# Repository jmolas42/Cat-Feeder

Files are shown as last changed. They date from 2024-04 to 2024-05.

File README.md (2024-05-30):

# Cat-Feeder

## Distributeur automatique de nourriture pour chat

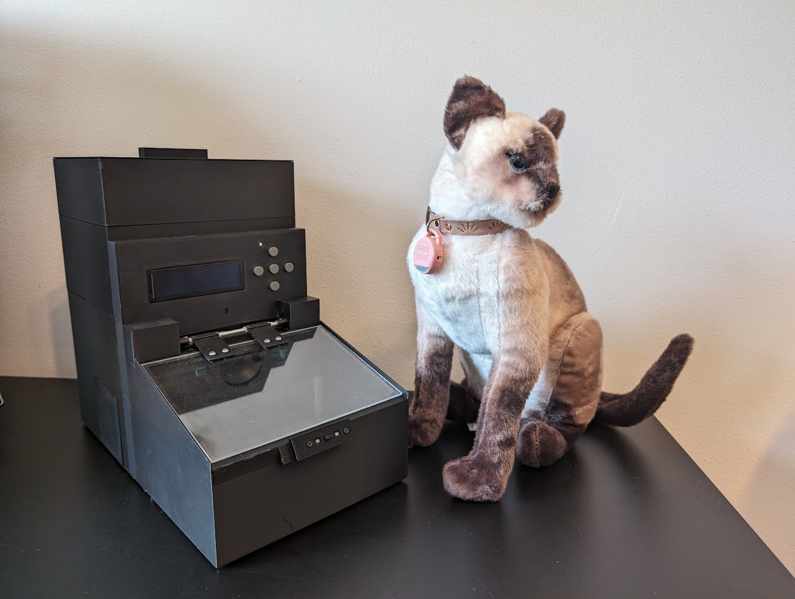
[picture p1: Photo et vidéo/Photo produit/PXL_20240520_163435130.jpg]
Cat Feeder


Préparez-vous à une innovation majeure dans la gestion alimentaire de vos compagnons félins ! Le distributeur automatique pour chats est une solution ingénieuse qui prend en charge la nourriture de votre animal de compagnie de manière autonome et efficace. Plus besoin de vous soucier des repas de votre chat, laissez cet appareil révolutionnaire s'occuper de tout, vous offrant ainsi une tranquillité d'esprit totale. Avec cette technologie de pointe, simplifiez votre quotidien et offrez à votre félin une expérience alimentaire optimale, tout en vous concentrant sur les moments importants de la vie.

## Gestion automatique et sécurisée pour les repas de votre chat

### Fonctionnalités :
- **Entièrement configurable** : Ajustez les paramètres selon les besoins spécifiques de votre chat.
- **Distribution automatique des croquettes à certaines heures** : Assure une alimentation régulière et équilibrée.
- **Porte qui s’ouvre seulement pour le chat autorisé** : Grâce à une balise dans le cou du chat, garantissant un accès sécurisé à la nourriture.
- **Connecté au WiFi** : Permet une gestion à distance et synchronisation des horaires.
- **Balance intégrée** : Surveille le poids du bol et enregistre l’appétit du chat via un site web dédié.
- **Système de secours pour l’alimentation** : Fonctionne avec des piles en cas de coupure de courant, assurant une continuité de service.

## Installation et Configuration :
1. **Insérez les piles** dans le distributeur et la balise pour assurer leur bon fonctionnement.
2. **Configurez l'appareil** une fois pour définir les heures de distribution des repas et les paramètres personnalisés.
3. **Profitez** de la gestion automatisée des repas de votre chat, offrant une alimentation régulière et surveillée.

Avec le Cat-Feeder, offrez à votre félin une alimentation optimisée et simplifiez-vous la vie !

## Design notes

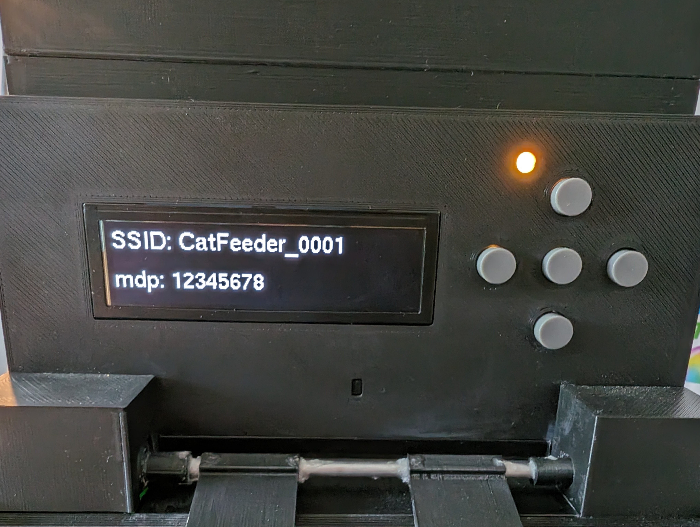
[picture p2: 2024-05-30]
Photo et vidéo/Photo produit/PXL_20240529_175449624.MP.jpg

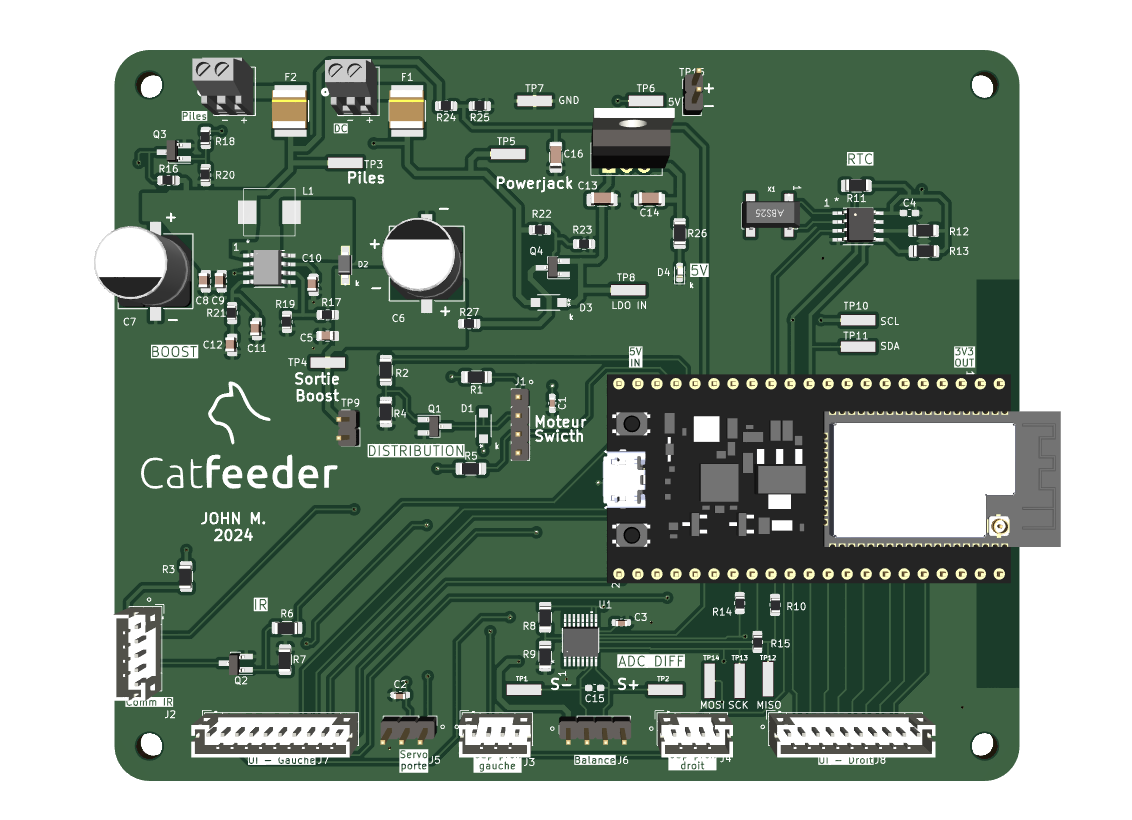
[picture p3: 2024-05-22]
Photo et vidéo/Photo PCB/PCB distributeur.png

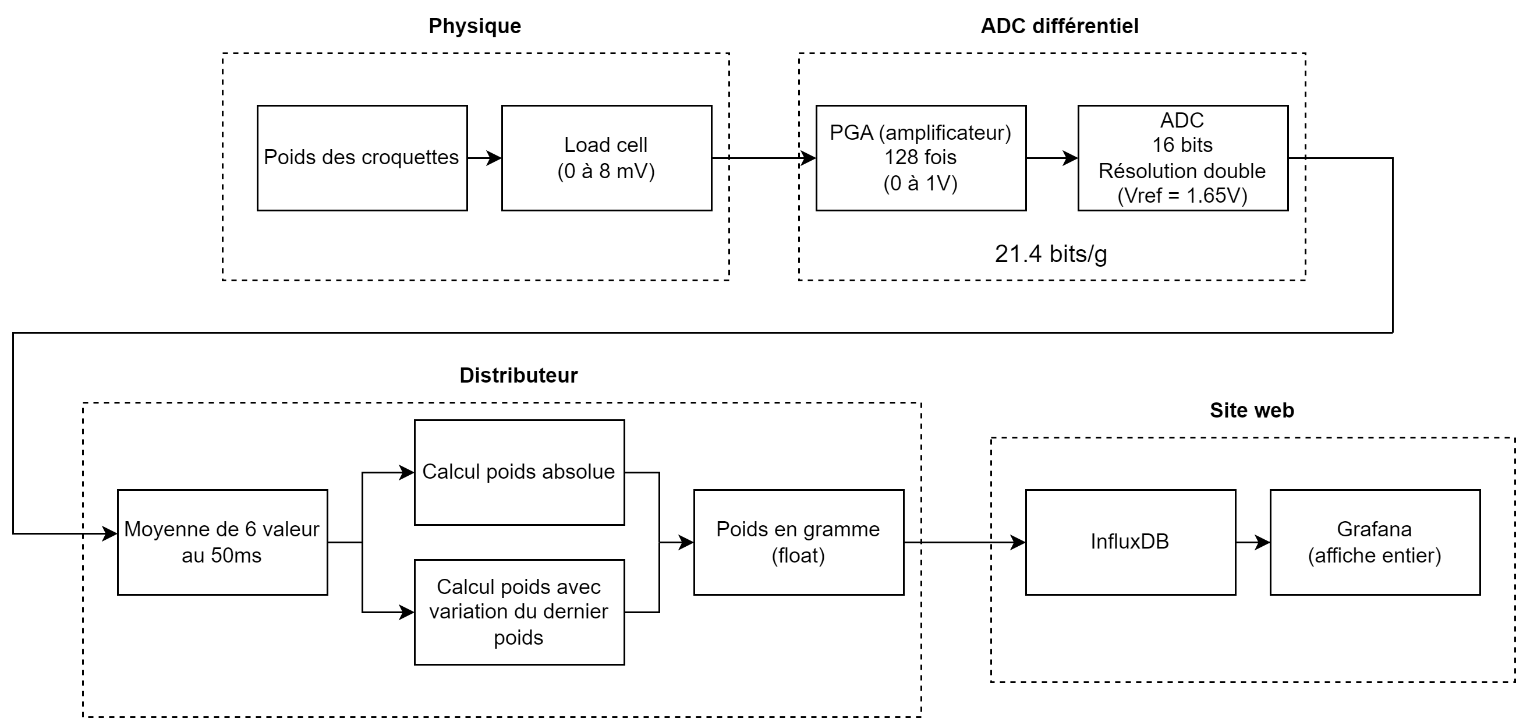
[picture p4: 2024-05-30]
Schémas/Schéma de principes/schema_balance.png

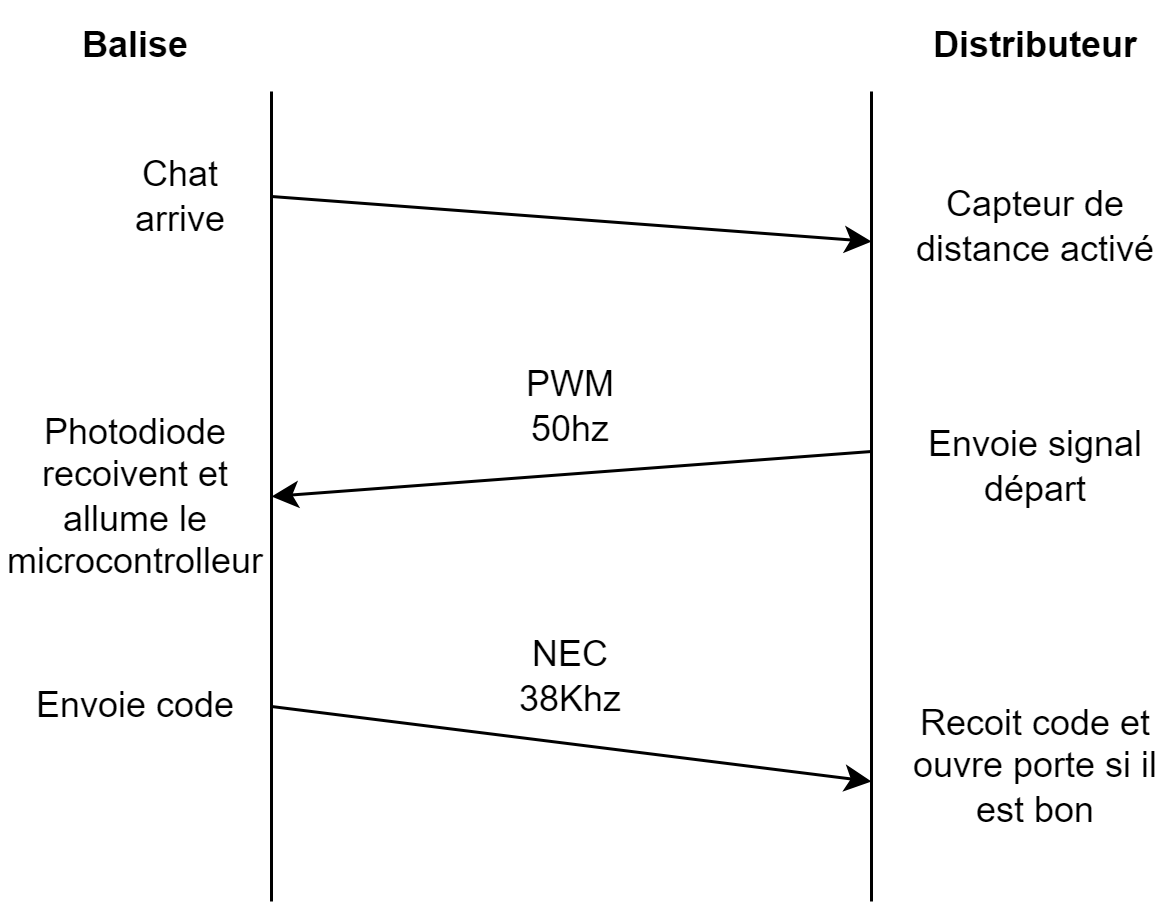
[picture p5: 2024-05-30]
Schémas/Schéma de principes/comm IR.drawio.png

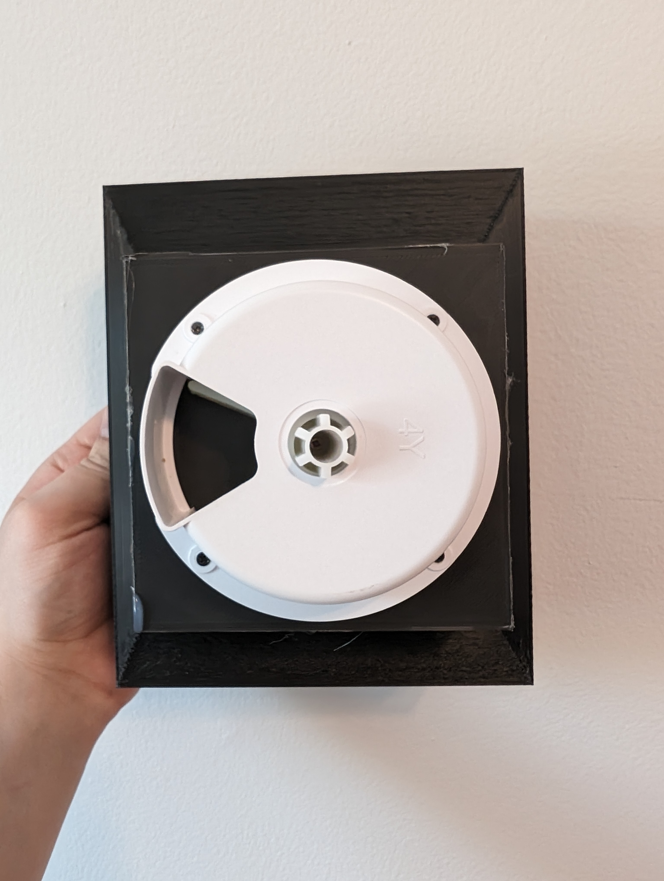
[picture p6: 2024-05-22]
Photo et vidéo/Photo produit/PXL_20240522_155029285.NIGHT.jpg

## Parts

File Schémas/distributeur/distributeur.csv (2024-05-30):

# | Reference | Qty | Value | Footprint | DNP
1 | C1, C2, C3, C4, C15 | 5 | ~ | Capacitor_SMD:C_0603_1608Metric_Pad1.08x0.95mm_HandSolder
2 | C5, C8 | 2 | 10u | Capacitor_SMD:C_0805_2012Metric_Pad1.18x1.45mm_HandSolder
3 | C6, C7 | 2 | 470u | cap_dig:CAP_EEE_G_PAN-M
4 | C9 | 1 | 1u | Capacitor_SMD:C_0805_2012Metric_Pad1.18x1.45mm_HandSolder
5 | C10 | 1 | 10n | Capacitor_SMD:C_0805_2012Metric_Pad1.18x1.45mm_HandSolder
6 | C11 | 1 | 47p | Capacitor_SMD:C_0805_2012Metric_Pad1.18x1.45mm_HandSolder
7 | C12 | 1 | 2.2n | Capacitor_SMD:C_0805_2012Metric_Pad1.18x1.45mm_HandSolder
8 | C13 | 1 | 1u | Capacitor_SMD:C_1206_3216Metric_Pad1.33x1.80mm_HandSolder
9 | C14 | 1 | 10u | Capacitor_SMD:C_1206_3216Metric_Pad1.33x1.80mm_HandSolder
10 | D1, D3 | 2 | 1N4007FL | 1n4007:CR_SOD-123FL_SME-M
11 | D2 | 1 | SS34LW | SS34LWH:SODFL3718X102N
12 | D4 | 1 | LED | LED_SMD:LED_0603_1608Metric_Pad1.05x0.95mm_HandSolder
13 | F1, F2 | 2 | Fuse | MF_SMDF050_2:FUSE_SMDF050-2
14 | J1 | 1 | Distribution | Connector_PinHeader_2.54mm:PinHeader_1x04_P2.54mm_Vertical
15 | J2 | 1 | ~ | Connector_JST:JST_PH_B5B-PH-K_1x05_P2.00mm_Vertical
16 | J3, J4 | 2 | ~ | Connector_JST:JST_PH_B4B-PH-K_1x04_P2.00mm_Vertical
17 | J5 | 1 | Servomoteur porte | Connector_PinHeader_2.54mm:PinHeader_1x03_P2.54mm_Vertical
18 | J6 | 1 | Cellule de charge | Connector_PinHeader_2.54mm:PinHeader_1x04_P2.54mm_Vertical
19 | J7, J8 | 2 | Conn_01x10 | Connector_JST:JST_PH_B10B-PH-K_1x10_P2.00mm_Vertical
20 | J9 | 1 | Powerjack | OST:CONN_OSTVN02A150_OST
21 | J10 | 1 | Piles | OST:CONN_OSTVN02A150_OST
22 | L1 | 1 | 6.8u | Library:TMPA 0603S
23 | Q1, Q2, Q3 | 3 | PJA3432-AU_R1 | Package_TO_SOT_SMD:SOT-23_Handsoldering
24 | Q4 | 1 | DMP3068L | Package_TO_SOT_SMD:SOT-23_Handsoldering
25 | R1 | 1 | 0R | Resistor_SMD:R_1206_3216Metric_Pad1.30x1.75mm_HandSolder
26 | R2, R6 | 2 | 100 | Resistor_SMD:R_1206_3216Metric_Pad1.30x1.75mm_HandSolder
27 | R3 | 1 | 51 | Resistor_SMD:R_1206_3216Metric_Pad1.30x1.75mm_HandSolder
28 | R4, R5, R7, R11, R12, R13 | 6 | 10k | Resistor_SMD:R_1206_3216Metric_Pad1.30x1.75mm_HandSolder
29 | R8 | 1 | 330k | Resistor_SMD:R_1206_3216Metric_Pad1.30x1.75mm_HandSolder
30 | R9 | 1 | 510k | Resistor_SMD:R_1206_3216Metric_Pad1.30x1.75mm_HandSolder
31 | R10, R14, R15, R27 | 4 | 0R | Resistor_SMD:R_0805_2012Metric_Pad1.20x1.40mm_HandSolder
32 | R16, R19, R23 | 3 | 10k | Resistor_SMD:R_0805_2012Metric_Pad1.20x1.40mm_HandSolder
33 | R17 | 1 | 34.9k | Resistor_SMD:R_0805_2012Metric_Pad1.20x1.40mm_HandSolder
34 | R18, R22 | 2 | 100 | Resistor_SMD:R_0805_2012Metric_Pad1.20x1.40mm_HandSolder
35 | R20 | 1 | 1k | Resistor_SMD:R_0805_2012Metric_Pad1.20x1.40mm_HandSolder
36 | R21 | 1 | 51k | Resistor_SMD:R_0805_2012Metric_Pad1.20x1.40mm_HandSolder
37 | R24 | 1 | 230k | Resistor_SMD:R_0805_2012Metric_Pad1.20x1.40mm_HandSolder
38 | R25 | 1 | 510k | Resistor_SMD:R_0805_2012Metric_Pad1.20x1.40mm_HandSolder
39 | R26 | 1 | 1.5k | Resistor_SMD:R_1206_3216Metric_Pad1.30x1.75mm_HandSolder
40 | TP1, TP2, TP3, TP4, TP5, TP6, TP7, TP8, TP10, TP11, TP12, TP13, TP14 | 13 | ~ | RCWCTE:TP420X150
41 | TP15 | 1 | 5V | Connector_PinHeader_2.54mm:PinHeader_1x02_P2.54mm_Vertical
42 | U1 | 1 | MAX11213EEE+ | MAX11213:21-0055H_16_MXM-M
43 | U2 | 1 | DS1337S+T&R | DS1337:21-0041B_8_MXM-M
44 | U3 | 1 | ESP32-S2-Saola-1 | PCM_Espressif:ESP32-S2-Saola-1
45 | U4 | 1 | PAM2423AECADJR | pam_dig:SOP-8_PAM2423AECADJR_DIO-M
46 | U5 | 1 | MIC2940A 5V | Package_TO_SOT_THT:TO-220-3_Vertical
47 | X1 | 1 | 32.768KHz | ABS25_32_768KHZ_6_1_T:XTAL_ABS25-32.768KHZ-6-1-T

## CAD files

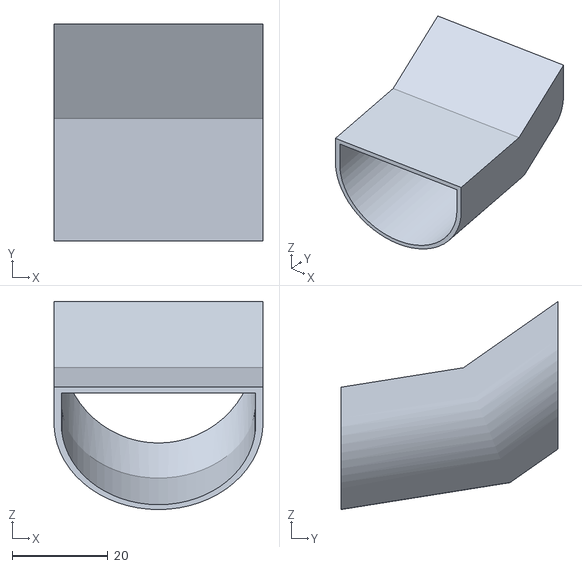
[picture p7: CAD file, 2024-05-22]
3D/chute croquette.stl
43.7 x 45.5 x 43.6

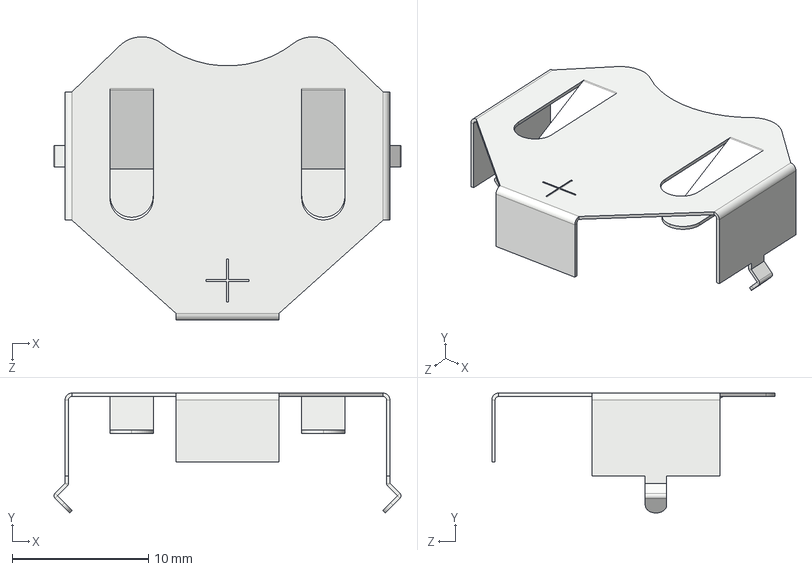
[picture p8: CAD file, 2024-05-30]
Schémas/Balise/3D/3011.step
25.5 x 8.80 x 20.8 mm

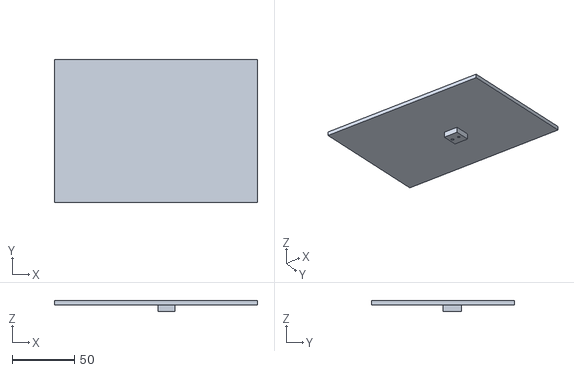
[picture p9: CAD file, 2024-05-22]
3D/support load cell - dessus.stl
163.7 x 115.7 x 8.50

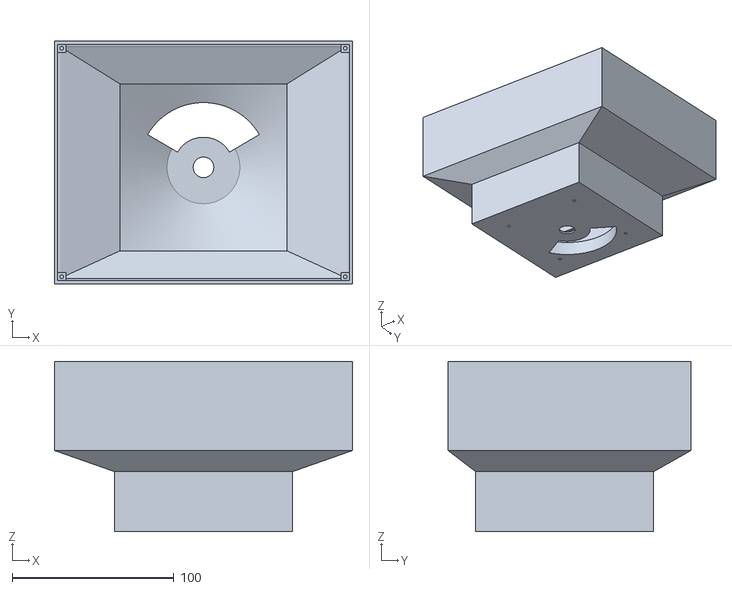
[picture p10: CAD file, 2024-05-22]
3D/réserve croquette.stl
184.0 x 150.0 x 105.0

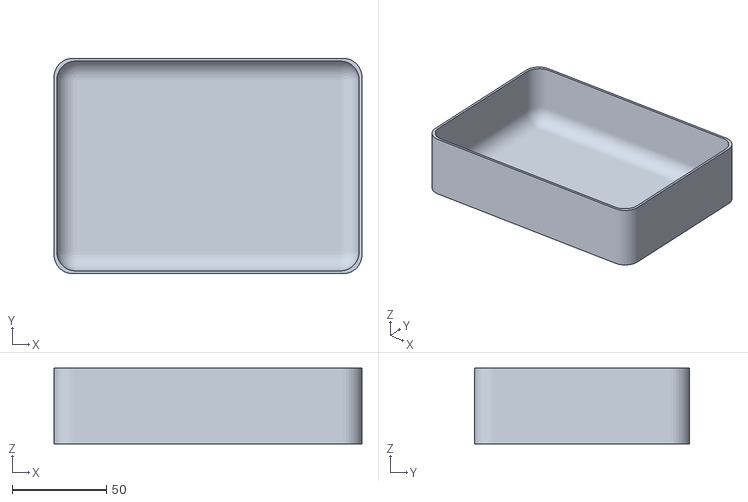
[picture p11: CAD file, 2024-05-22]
3D/bol.stl
163.0 x 114.0 x 40.0

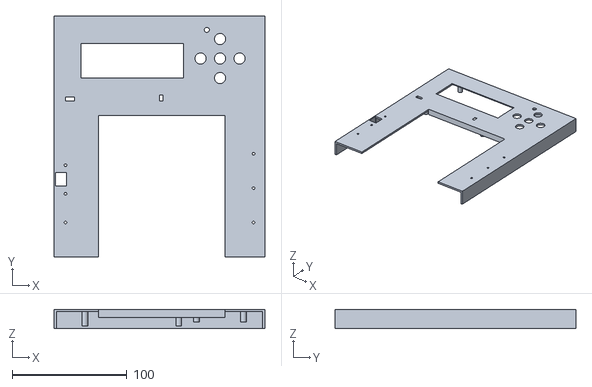
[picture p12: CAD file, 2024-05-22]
3D/face avant.stl
184.0 x 210.0 x 17.0

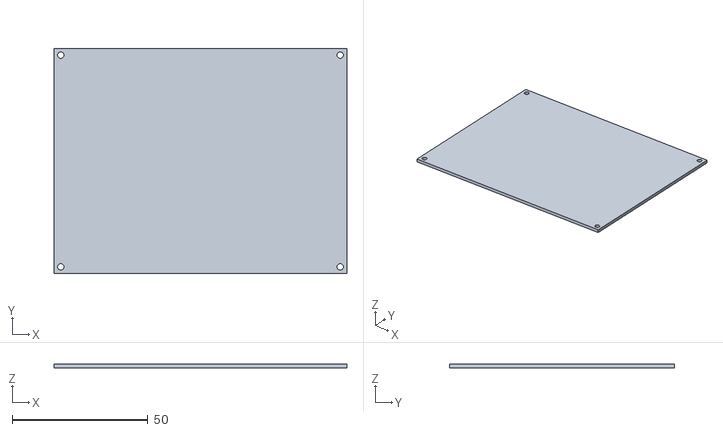
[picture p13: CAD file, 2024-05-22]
3D/porte holder batterie.stl
108.0 x 83.0 x 1.50

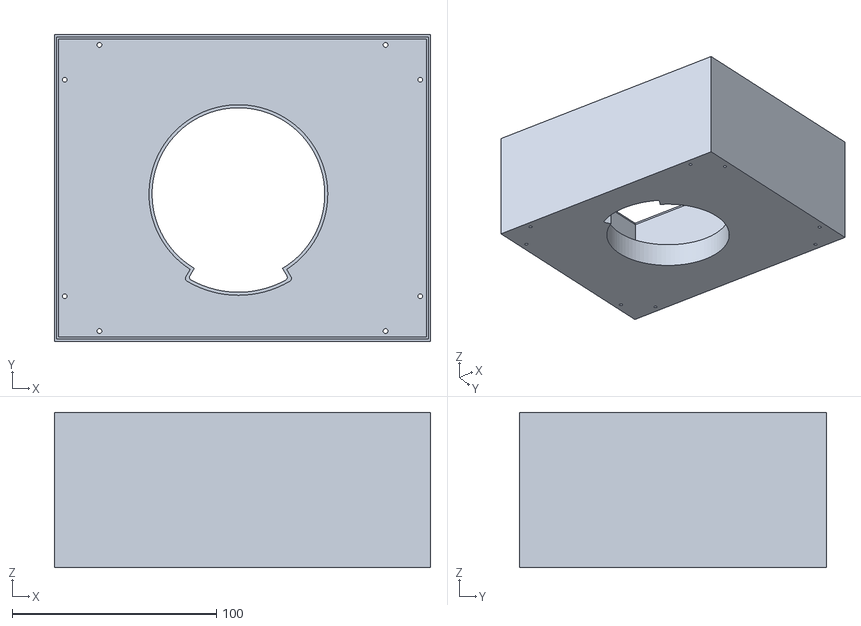
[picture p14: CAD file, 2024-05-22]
3D/base réserve bouffe.stl
184.0 x 150.0 x 75.9

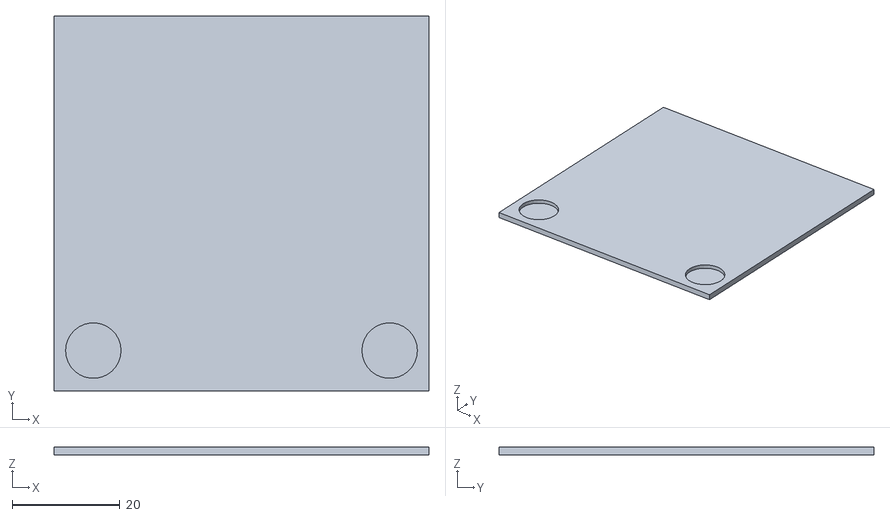
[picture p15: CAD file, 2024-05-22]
3D/porte distributrice arriere gauche avec aimant.stl
69.6 x 69.6 x 1.50

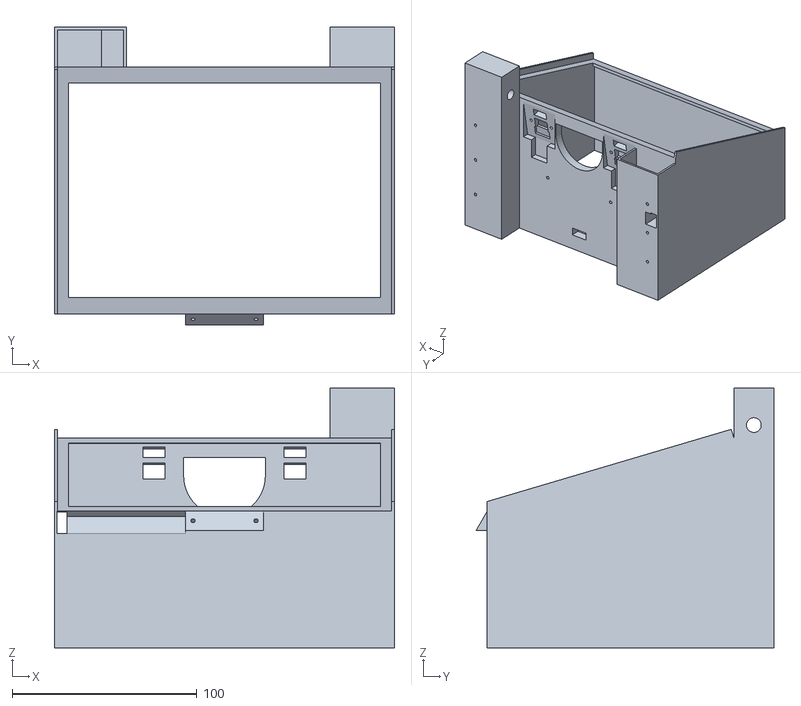
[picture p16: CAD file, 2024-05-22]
3D/devant distributrice.stl
184.0 x 161.1 x 140.6

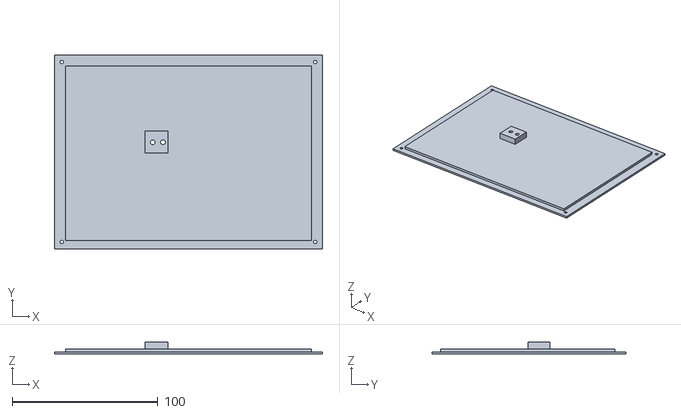
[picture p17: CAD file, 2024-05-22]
3D/support load cell - dessous.stl
184.0 x 133.5 x 8.50

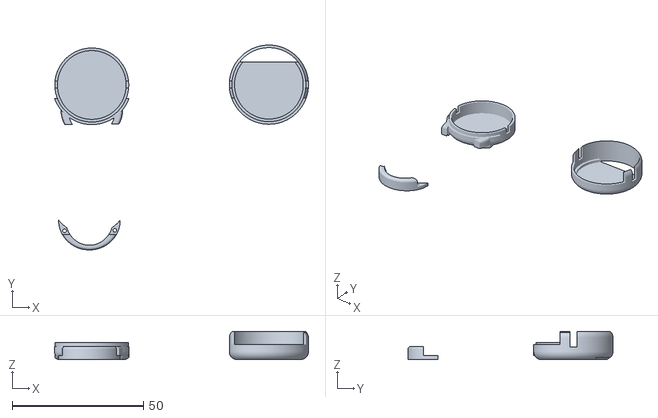
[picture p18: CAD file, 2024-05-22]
3D/boitier balise.stl
96.8 x 78.1 x 10.7

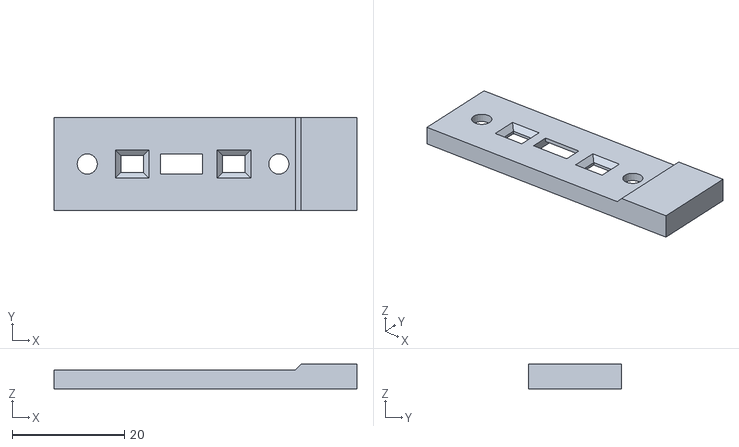
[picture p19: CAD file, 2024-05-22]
3D/cache PCB IR.stl
54.0 x 16.5 x 4.40

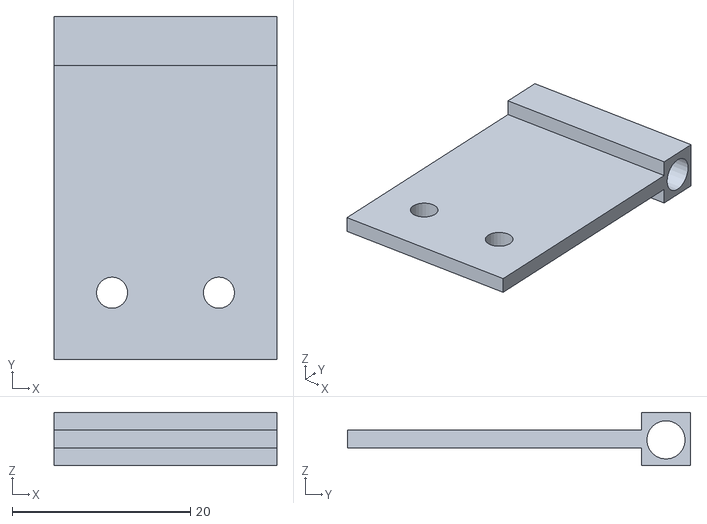
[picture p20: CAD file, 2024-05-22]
3D/serre porte.stl
25.0 x 38.5 x 6.00

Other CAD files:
3D/derriere distributrice.stl
3D/adapteur gougeon.stl
3D/cache servo.stl
3D/support additionnel vertical.stl
3D/adapteur servo.stl
3D/cache fils IR.stl
3D/couvercle réserve bouffe.stl
3D/plateau distribution.stl
3D/support additionnel horizontal.stl

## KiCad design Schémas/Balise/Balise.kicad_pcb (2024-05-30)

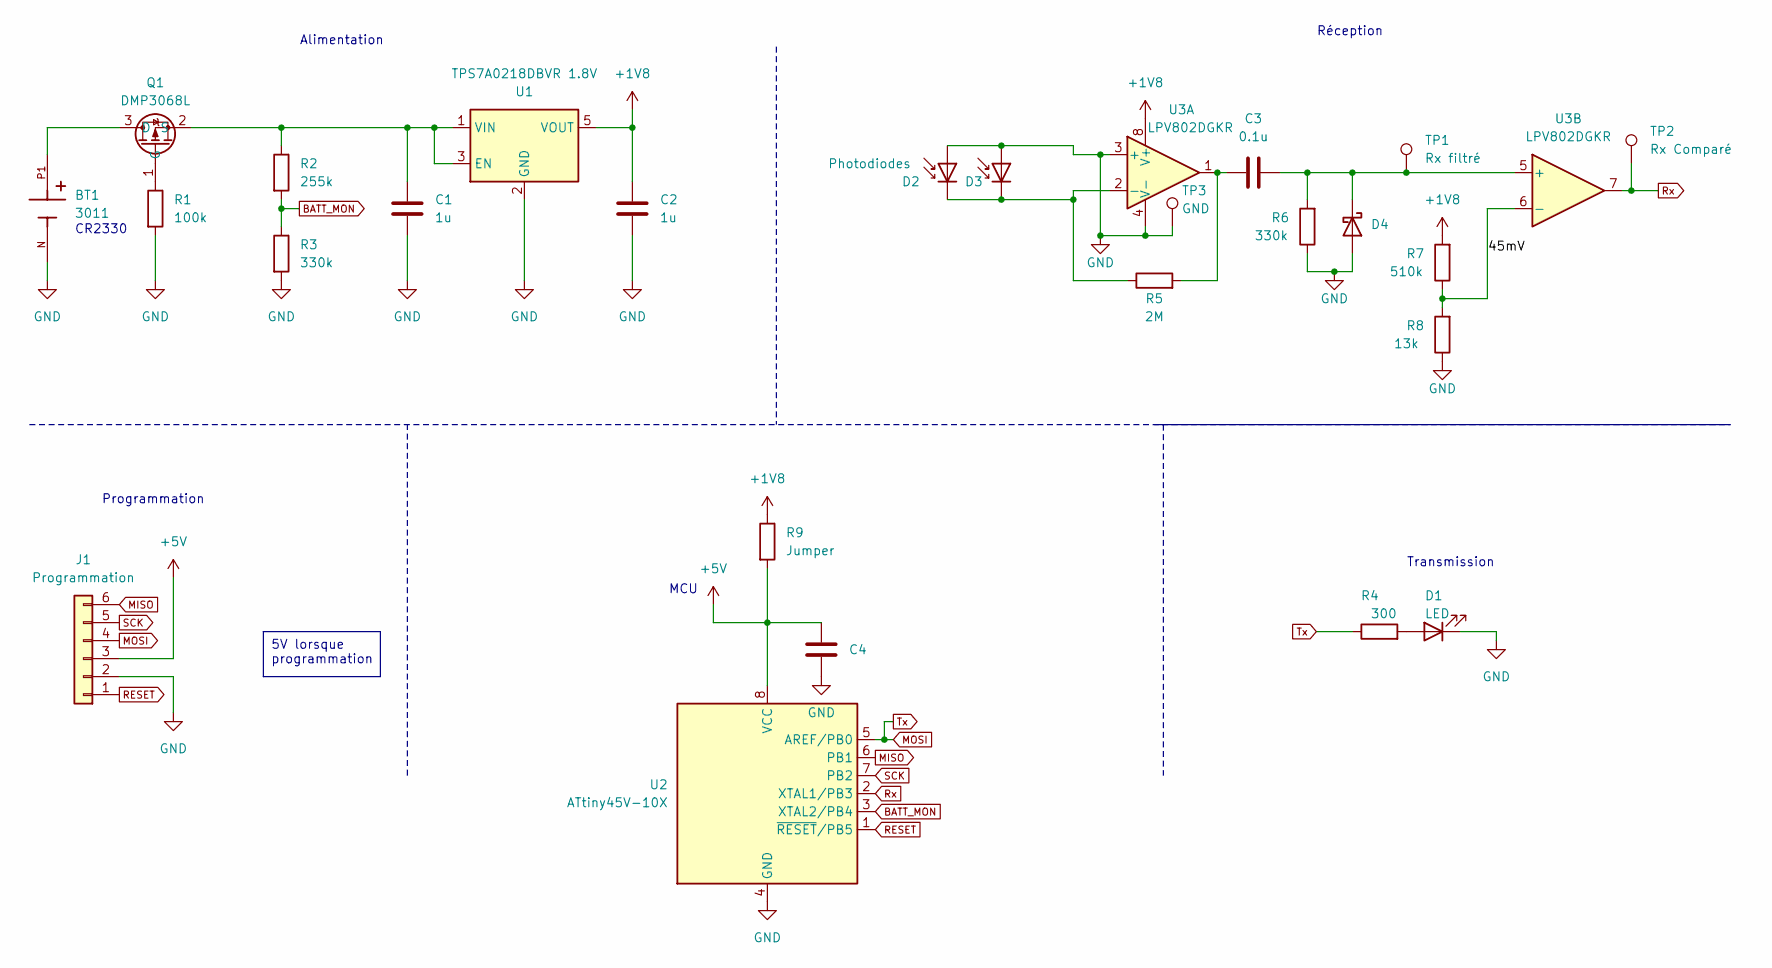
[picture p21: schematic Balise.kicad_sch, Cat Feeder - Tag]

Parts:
BT1: 3011; BAT_3011; PARTREV B
C1, C2: 1u; C_0603_1608Metric_Pad1.08x0.95mm_HandSolder
C3: 0.1u; C_0603_1608Metric_Pad1.08x0.95mm_HandSolder
C4: C_0603_1608Metric_Pad1.08x0.95mm_HandSolder
D1: LED; LED_0603_1608Metric_Pad1.05x0.95mm_HandSolder
D2: Photodiodes; LED_0805_2012Metric_Pad1.15x1.40mm_HandSolder
D3: D_Photo; LED_0805_2012Metric_Pad1.15x1.40mm_HandSolder
D4: D_Schottky; D_0603_1608Metric_Pad1.05x0.95mm_HandSolder
J1: Programmation; Tag-Connect_TC2030-IDC-NL_2x03_P1.27mm_Vertical
Q1: DMP3068L; SOT-23
R1: 100k; R_0603_1608Metric_Pad0.98x0.95mm_HandSolder
R2: 255k; R_0603_1608Metric_Pad0.98x0.95mm_HandSolder
R3, R6: 330k; R_0603_1608Metric_Pad0.98x0.95mm_HandSolder
R4: 300; R_0603_1608Metric_Pad0.98x0.95mm_HandSolder
R5: 2M; R_0603_1608Metric_Pad0.98x0.95mm_HandSolder
R7: 510k; R_0603_1608Metric_Pad0.98x0.95mm_HandSolder
R8: 13k; R_0603_1608Metric_Pad0.98x0.95mm_HandSolder
R9: Jumper; R_0603_1608Metric_Pad0.98x0.95mm_HandSolder
TP1: Rx filtré; HARWIN_S2751-46R
TP2: Rx Comparé; HARWIN_S2751-46R
TP3: GND; HARWIN_S2751-46R
U1: TPS7A0218DBVR 1.8V; TSOT-23-5
U2: ATtiny45V-10X; TSSOP-8_4.4x3mm_P0.65mm
U3: LPV802DGKR; VSSOP-8_3.0x3.0mm_P0.65mm

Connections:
+1V8: C2.1, R7.2, R9.1, U1.5 (VOUT), U3.8 (V+)
+5V: C4.1, J1.3, R9.2, U2.8 (VCC)
/45mV: R7.1, R8.2, U3.6 (-)
BATT_MON: R2.2, R3.1, U2.3 (XTAL2/PB4)
GND: BT1.N, C1.2, C2.2, C4.2, D1.1 (K), D2.2 (A), D3.2 (A), D4.2 (A), J1.2, R1.2, R3.2, R6.1, R8.1, TP3.1, U1.2 (GND), U2.4 (GND), U3.3 (+), U3.4 (V-)
MISO: J1.6, U2.6 (PB1)
MOSI: J1.4, R4.1, U2.5 (AREF/PB0)
unnamed: C3.1, R5.2, U3.1
unnamed: D1.2 (A), R4.2
unnamed: D2.1 (K), D3.1 (K), R5.1, U3.2 (-)
unnamed: C3.2, D4.1 (K), R6.2, TP1.1, U3.5 (+)
unnamed: BT1.P1, Q1.3 (D)
unnamed: Q1.1 (G), R1.1
unnamed: C1.1, Q1.2 (S), R2.1, U1.1 (VIN), U1.3 (EN)
RESET: J1.1, U2.1 (~RESET/PB5)
Rx: TP2.1, U2.2 (XTAL1/PB3), U3.7
SCK: J1.5, U2.7 (PB2)

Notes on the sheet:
5V lorsque programmation
CR2330
MCU
Alimentation
Programmation
Transmission
Réception

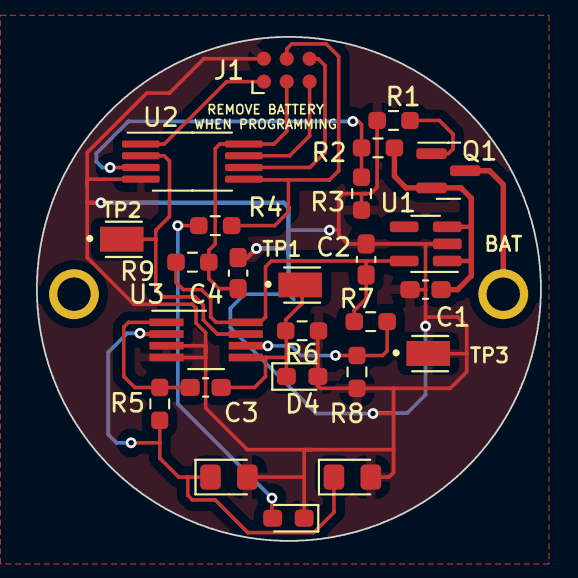
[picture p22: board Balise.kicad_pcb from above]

Board: 2 copper layers, 28.0 x 28.0 mm, 26 parts (1 on the bottom side), 17 nets.

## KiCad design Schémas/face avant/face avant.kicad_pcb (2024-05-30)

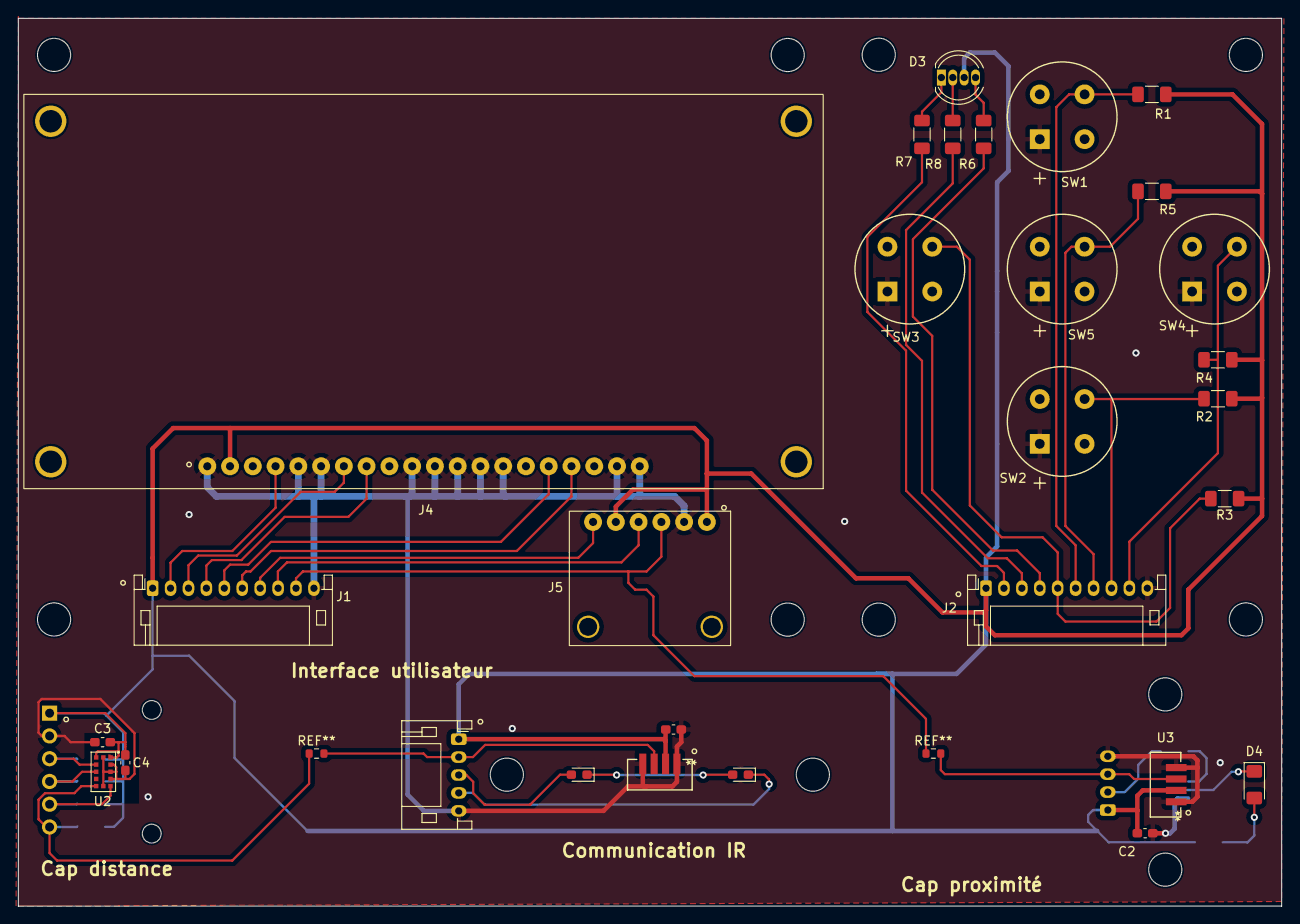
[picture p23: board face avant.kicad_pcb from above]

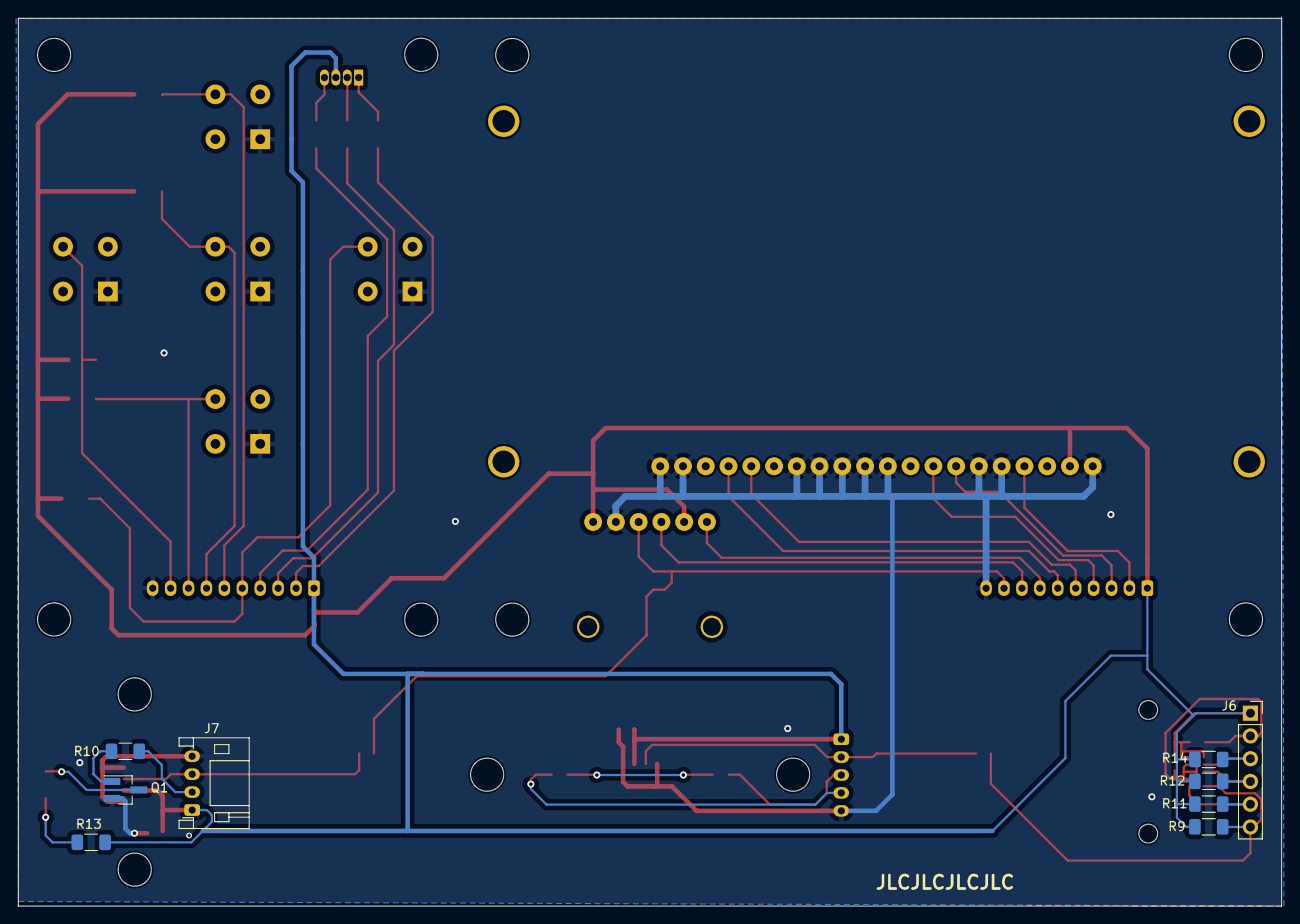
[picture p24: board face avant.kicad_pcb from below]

Board: 2 copper layers, 141.0 x 99.1 mm, 38 parts (9 on the bottom side), 34 nets.

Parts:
C1, C2: C_0603_1608Metric_Pad1.08x0.95mm_HandSolder
C3: 100n; C_0603_1608Metric_Pad1.08x0.95mm_HandSolder
C4: 4.7u; C_0603_1608Metric_Pad1.08x0.95mm_HandSolder
D1, D2: LED; LED_0603_1608Metric_Pad1.05x0.95mm_HandSolder
D3: QBL8RGB25C0; LED_D5.0mm-4_RGB
D4: LED; LED_1206_3216Metric_Pad1.42x1.75mm_HandSolder
J1, J2: Conn_01x10; JST_PH_S10B-PH-K_1x10_P2.00mm_Horizontal
J3: Conn_01x05; JST_PH_S5B-PH-K_1x05_P2.00mm_Horizontal
J4: NHD-3.12-25664UCW2; Screen
J5: vers VL53L4CDV0DH; Cap dist
J6: PinHeader_1x06_P2.54mm_Vertical
J7: Conn_01x04; JST_PH_S4B-PH-K_1x04_P2.00mm_Horizontal
Q1: PJA3432-AU_R1; SOT-23_Handsoldering
R1, R2, R3, R4, R5, R9, R11, R12, R14: 10k; R_1206_3216Metric_Pad1.30x1.75mm_HandSolder
R6, R7, R8: 220; R_1206_3216Metric_Pad1.30x1.75mm_HandSolder
R10: 100; R_1206_3216Metric_Pad1.30x1.75mm_HandSolder
R13: 40; R_1206_3216Metric_Pad1.30x1.75mm_HandSolder
SW1: Bouton haut; D6R_CNK
SW2: Bouton bas; D6R_CNK
SW3: Bouton gauche; D6R_CNK
SW4: Bouton droit; D6R_CNK
SW5: Bouton sélection; D6R_CNK
U1: TSOP75338TT; TSOP75338WTT_VIS-M
U2: VL53L4CDV0DH; XDCR_VL53L3CXV0DH_1
U3: TSOP75438WTR; TSOP75338WTT_VIS-M

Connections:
+3V3: C1.1, C2.1, C3.1, C4.1, D3.3 (A), J1.1, J2.1, J3.1, J4.2, J5.1, J5.5, J6.1, J7.1, R1.1, R2.1, R3.1, R4.1, R5.1, R9.2, R11.2, R12.2, R13.2, R14.2, U1.2 (VS), U2.1 (AVDDVCSEL), U2.11 (AVDD), U3.2 (VS)
BOUT_BAS: J2.8, R2.2, SW2.3
BOUT_DROIT: J2.9, R4.2, SW4.3
BOUT_GAUCHE: J2.5, R3.2, SW3.3
BOUT_HAUT: J2.6, R1.2, SW1.3
BOUT_SELECT: J2.7, R5.2, SW5.3
D/C_ecran: J1.2, J4.4
GND: C1.2, C2.2, C3.2, C4.2, J1.10, J2.10, J3.5, J4.1, J4.5, J4.6, J4.10, J4.11, J4.12, J4.13, J4.14, J4.19, J4.20, J5.2, J6.2, J7.4, Q1.2 (S), SW1.1, SW2.1, SW3.1, SW4.1, SW5.1, U1.1 (GND), U1.4 (GND), U2.2 (AVSSVCSEL), U2.3 (GND), U2.4 (GND__1), U2.6 (GND__2), U2.12 (GND__3), U3.1 (GND), U3.4 (GND)
INT_cap-dis: J1.7, J5.6
unnamed: D1.2 (A), J3.3
unnamed: D1.1 (K), D2.2 (A)
unnamed: D2.1 (K), J3.4
unnamed: D3.2 (BK), R8.2
unnamed: D3.1 (GK), R7.2
unnamed: D3.4 (RK), R6.2
unnamed: D4.2 (A), R13.1
unnamed: D4.1 (K), Q1.3 (D)
unnamed: J3.2, U1.3 (OUT)
unnamed: J6.3, R14.1, U2.10 (SCL)
unnamed: J6.4, R12.1, U2.9 (SDA)
unnamed: J6.5, R11.1, U2.5 (XSHUT)
unnamed: J6.6, R9.1, U2.7 (GPIO1)
unnamed: J7.2, R10.1
unnamed: J7.3, U3.3 (OUT)
unnamed: Q1.1 (G), R10.2
RGB_B: J2.3, R8.1
RGB_G: J2.2, R7.1
RGB_R: J2.4, R6.1
SCLK_ecran: J1.3, J4.7
SCL_cap-dis: J1.9, J5.3
SDA_cap-dis: J1.8, J5.4
SDIN_ecran: J1.4, J4.8
/CS_ecran: J1.6, J4.17
/RES_ecran: J1.5, J4.16

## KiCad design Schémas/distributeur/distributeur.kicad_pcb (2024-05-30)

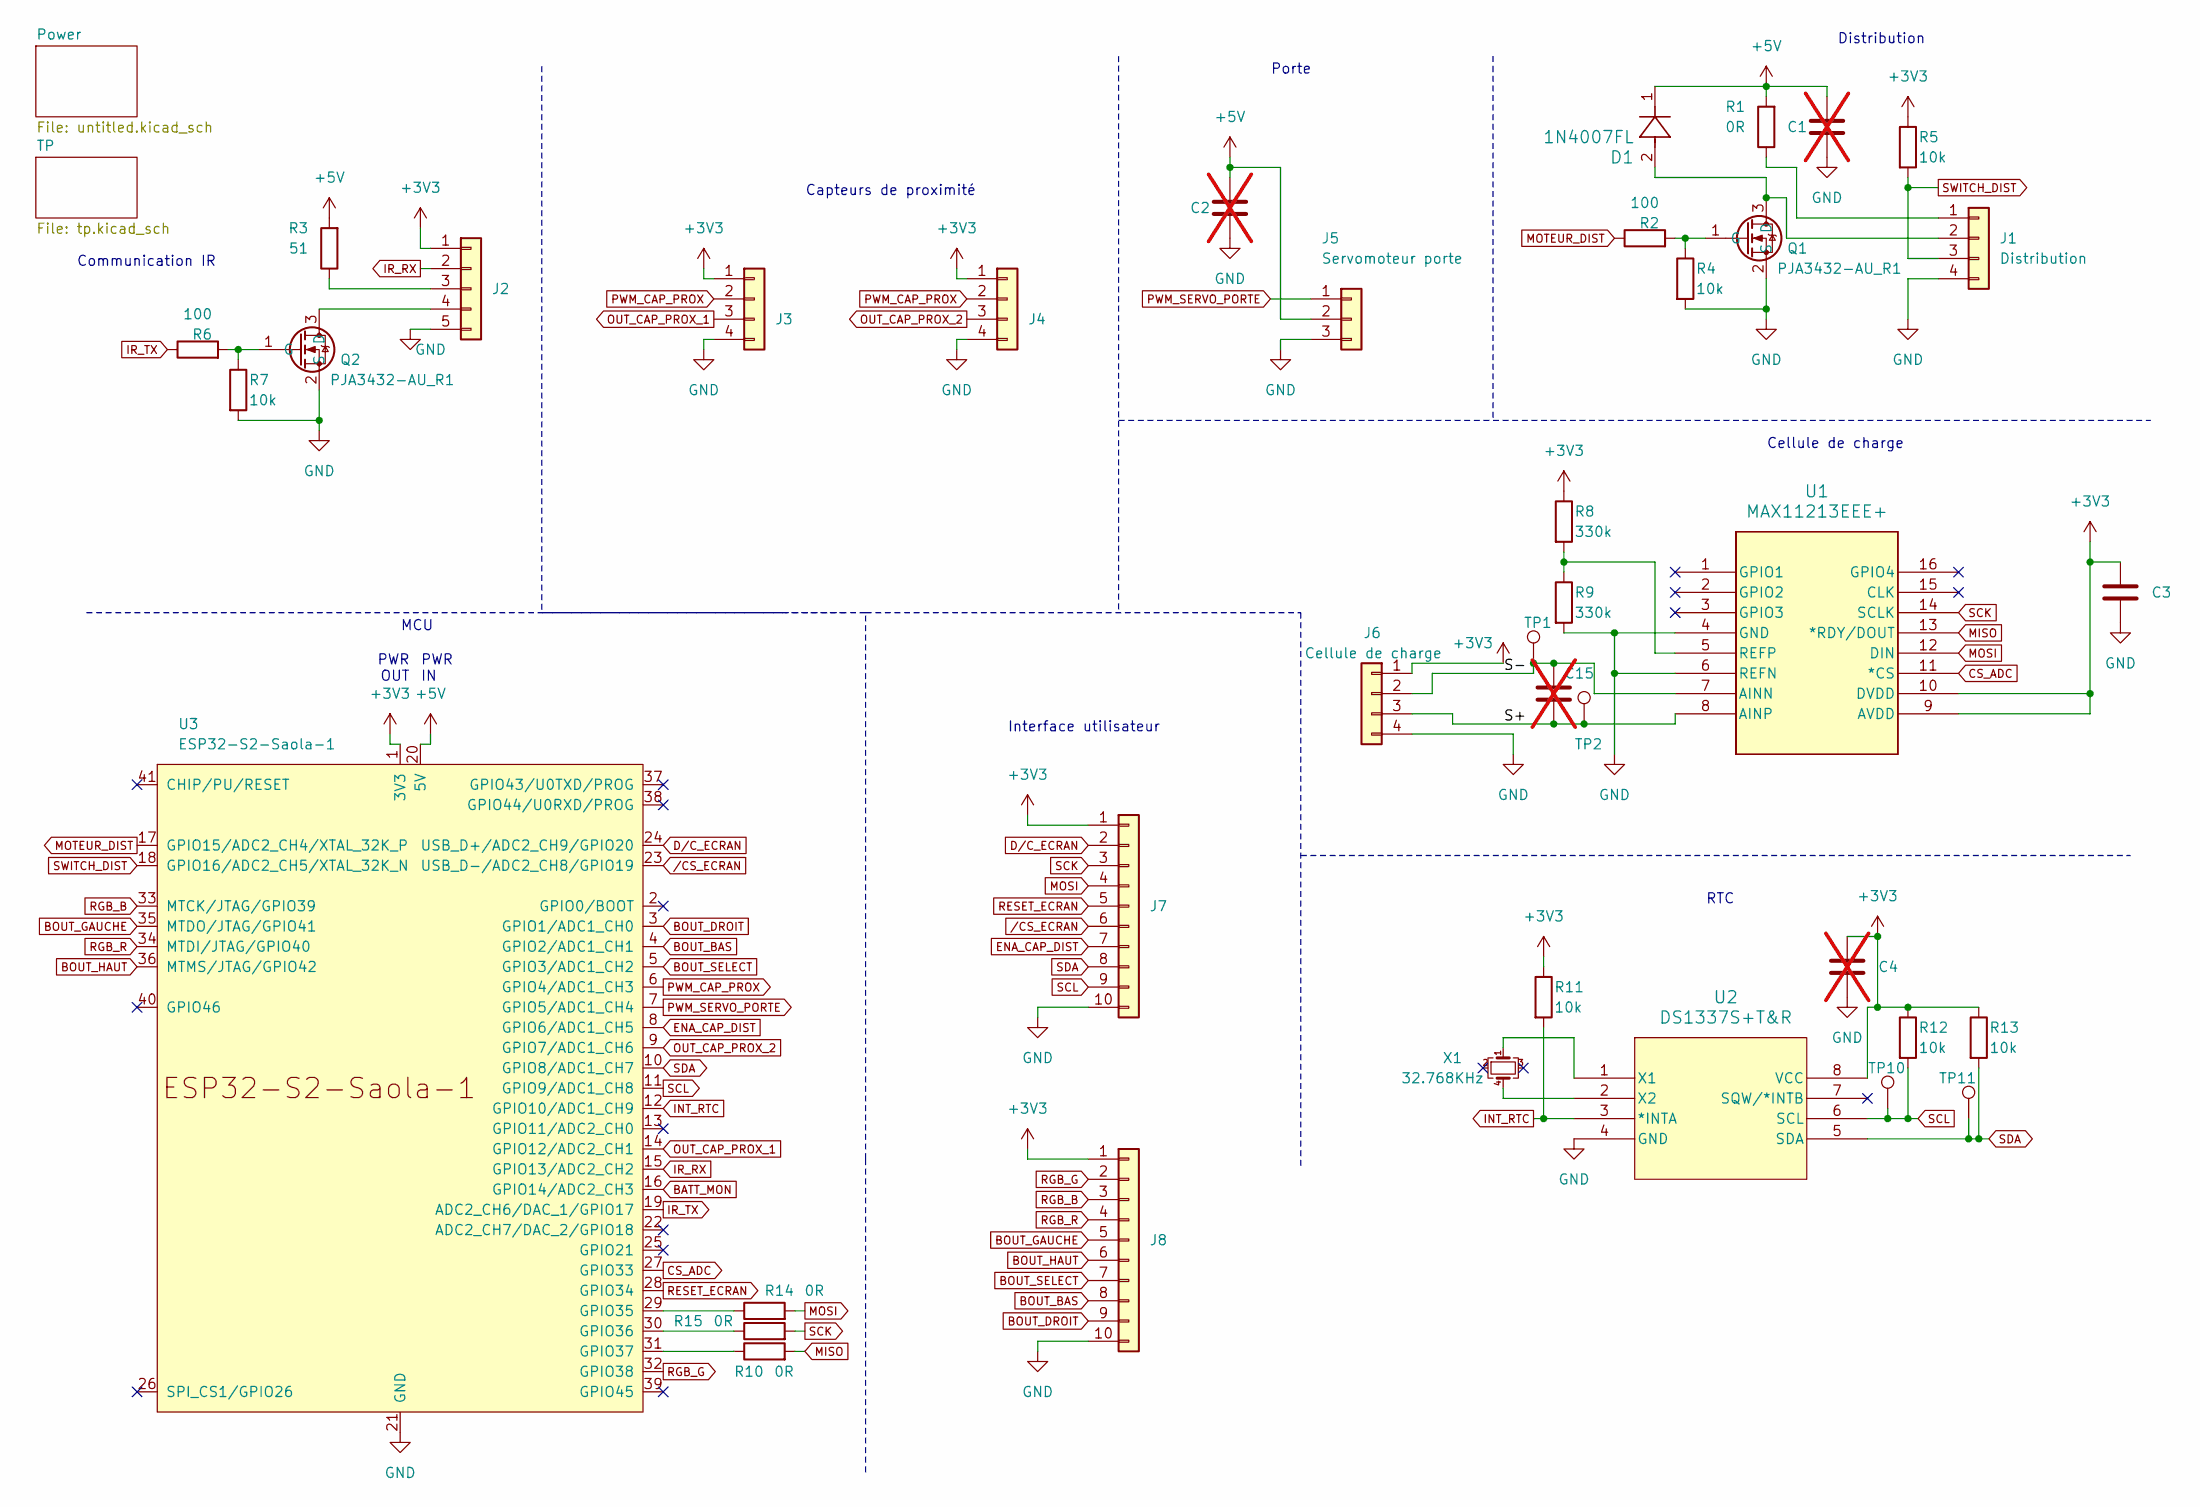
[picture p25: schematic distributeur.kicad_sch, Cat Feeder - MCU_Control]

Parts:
C1, C2, C4, C15: C_0603_1608Metric_Pad1.08x0.95mm_HandSolder; not fitted
C3: C_0603_1608Metric_Pad1.08x0.95mm_HandSolder
D1: 1N4007FL; CR_SOD-123FL_SME-M
J1: Distribution; PinHeader_1x04_P2.54mm_Vertical
J2: JST_PH_B5B-PH-K_1x05_P2.00mm_Vertical
J3, J4: JST_PH_B4B-PH-K_1x04_P2.00mm_Vertical
J5: Servomoteur porte; PinHeader_1x03_P2.54mm_Vertical
J6: Cellule de charge; PinHeader_1x04_P2.54mm_Vertical
J7, J8: Conn_01x10; JST_PH_B10B-PH-K_1x10_P2.00mm_Vertical
Q1, Q2: PJA3432-AU_R1; SOT-23_Handsoldering
R1: 0R; R_1206_3216Metric_Pad1.30x1.75mm_HandSolder
R2, R6: 100; R_1206_3216Metric_Pad1.30x1.75mm_HandSolder
R3: 51; R_1206_3216Metric_Pad1.30x1.75mm_HandSolder
R4, R5, R7, R11, R12, R13: 10k; R_1206_3216Metric_Pad1.30x1.75mm_HandSolder
R8, R9: 330k; R_1206_3216Metric_Pad1.30x1.75mm_HandSolder
R10, R14, R15: 0R; R_0805_2012Metric_Pad1.20x1.40mm_HandSolder
TP1, TP2, TP10, TP11: TP420X150
U1: MAX11213EEE+; 21-0055H_16_MXM-M
U2: DS1337S+T&R; 21-0041B_8_MXM-M
U3: ESP32-S2-Saola-1
X1: 32.768KHz; XTAL_ABS25-32.768KHZ-6-1-T

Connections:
+3V3: C3.1, C4.1, J2.1, J3.1, J4.1, J6.1, J7.1, J8.1, R5.1, R8.1, R11.1, R12.1, R13.1, U1.9 (AVDD), U1.10 (DVDD), U2.8 (VCC), U3.1 (3V3)
+5V: C1.1, C2.1, D1.1, J5.2, R1.2, R3.2, U3.20 (5V); also elsewhere on the board
/S+: C15.2, J6.3, TP2.1, U1.8 (AINP)
/S-: C15.1, J6.2, TP1.1, U1.7 (AINN)
BATT_MON: U3.16 (GPIO14/ADC2_CH3); also elsewhere on the board
BOUT_BAS: J8.8, U3.4 (GPIO2/ADC1_CH1)
BOUT_DROIT: J8.9, U3.3 (GPIO1/ADC1_CH0)
BOUT_GAUCHE: J8.5, U3.35 (MTDO/JTAG/GPIO41)
BOUT_HAUT: J8.6, U3.36 (MTMS/JTAG/GPIO42)
BOUT_SELECT: J8.7, U3.5 (GPIO3/ADC1_CH2)
CS_ADC: U1.11 (*CS), U3.27 (GPIO33)
D/C_ECRAN: J7.2, U3.24 (USB_D+/ADC2_CH9/GPIO20)
GND: C1.2, C2.2, C3.2, C4.2, J1.4, J2.5, J3.4, J4.4, J5.3, J6.4, J7.10, J8.10, Q1.2 (S), Q2.2 (S), R4.2, R7.2, R9.2, U1.4 (GND), U1.6 (REFN), U2.4 (GND), U3.21 (GND), U3.42 (GND); also elsewhere on the board
INT_CAP_DIST: J7.7, U3.8 (GPIO6/ADC1_CH5)
INT_RTC: R11.2, U2.3 (*INTA), U3.12 (GPIO10/ADC1_CH9)
IR_RX: J2.2, U3.15 (GPIO13/ADC2_CH2)
IR_TX: R6.1, U3.19 (ADC2_CH6/DAC_1/GPIO17)
MISO: R10.2, U1.13 (*RDY/DOUT); also elsewhere on the board
MOSI: J7.4, R14.2, U1.12 (DIN); also elsewhere on the board
MOTEUR_DIST: R2.1, U3.17 (GPIO15/ADC2_CH4/XTAL_32K_P)
unnamed: J1.1, R1.1
unnamed: D1.2, J1.2, Q1.3 (D)
unnamed: J2.3, R3.1
unnamed: J2.4, Q2.3 (D)
unnamed: Q1.1 (G), R2.2, R4.1
unnamed: Q2.1 (G), R6.2, R7.1
unnamed: R8.2, R9.1, U1.5 (REFP)
unnamed: U2.1 (X1), X1.1
unnamed: U2.2 (X2), X1.4
unnamed: R14.1, U3.29 (GPIO35)
unnamed: R15.1, U3.30 (GPIO36)
unnamed: R10.1, U3.31 (GPIO37)
OUT_CAP_PROX_1: J3.3, U3.14 (GPIO12/ADC2_CH1)
OUT_CAP_PROX_2: J4.3, U3.9 (GPIO7/ADC1_CH6)
PWM_CAP_PROX: J3.2, J4.2, U3.6 (GPIO4/ADC1_CH3)
PWM_SERVO_PORTE: J5.1, U3.7 (GPIO5/ADC1_CH4)
RESET_ECRAN: J7.5, U3.28 (GPIO34)
RGB_B: J8.3, U3.33 (MTCK/JTAG/GPIO39)
RGB_G: J8.2, U3.32 (GPIO38)
RGB_R: J8.4, U3.34 (MTDI/JTAG/GPIO40)
SCK: J7.3, R15.2, U1.14 (SCLK); also elsewhere on the board
SCL: J7.9, R12.2, TP10.1, U2.6 (SCL), U3.11 (GPIO9/ADC1_CH8)
SDA: J7.8, R13.2, TP11.1, U2.5 (SDA), U3.10 (GPIO8/ADC1_CH7)
SWITCH_DIST: J1.3, R5.2, U3.18 (GPIO16/ADC2_CH5/XTAL_32K_N)
/CS_ECRAN: J7.6, U3.23 (USB_D-/ADC2_CH8/GPIO19)

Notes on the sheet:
RTC
Porte
PWR IN
Communication IR
Distribution
Interface utilisateur
MCU
PWR OUT
Capteurs de proximité
Cellule de charge

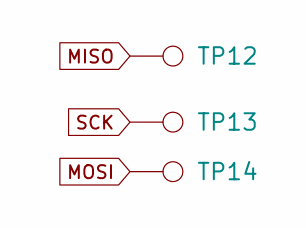
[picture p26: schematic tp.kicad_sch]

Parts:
TP12, TP13, TP14: TP420X150

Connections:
MISO: TP12.1; also elsewhere on the board
MOSI: TP14.1; also elsewhere on the board
SCK: TP13.1; also elsewhere on the board

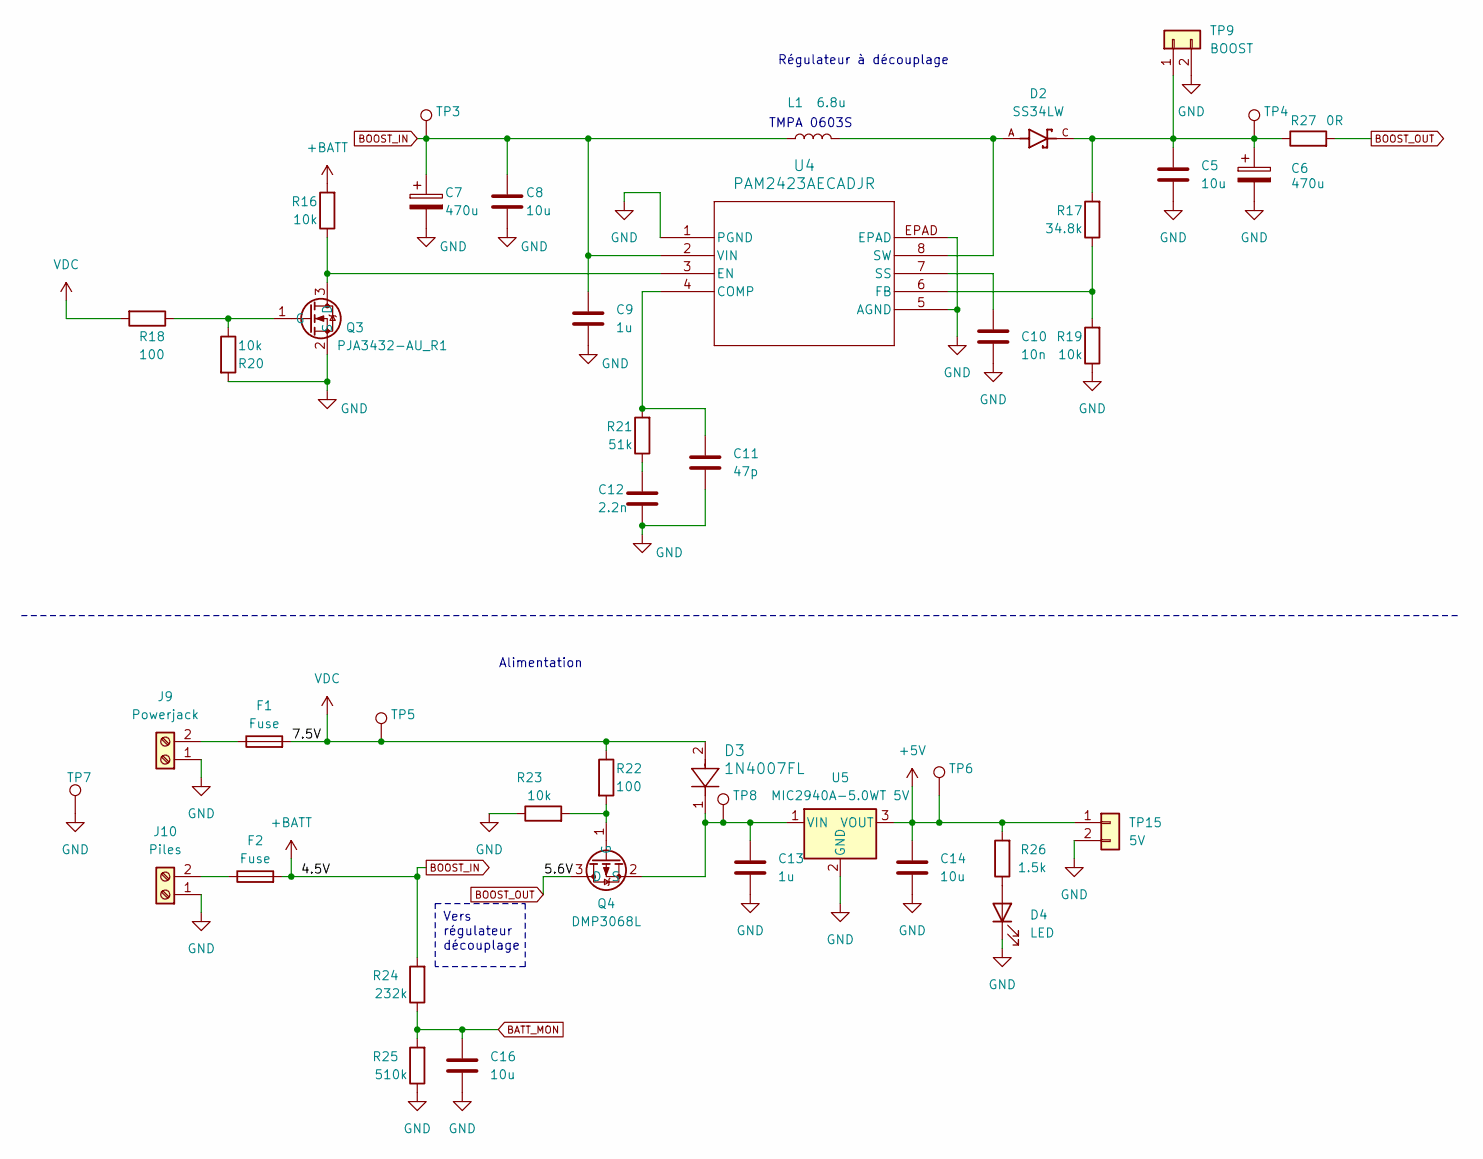
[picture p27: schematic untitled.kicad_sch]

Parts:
C5, C8: 10u; C_0805_2012Metric_Pad1.18x1.45mm_HandSolder
C6, C7: 470u; CAP_EEE_G_PAN-M
C9: 1u; C_0805_2012Metric_Pad1.18x1.45mm_HandSolder
C10: 10n; C_0805_2012Metric_Pad1.18x1.45mm_HandSolder
C11: 47p; C_0805_2012Metric_Pad1.18x1.45mm_HandSolder
C12: 2.2n; C_0805_2012Metric_Pad1.18x1.45mm_HandSolder
C13: 1u; C_1206_3216Metric_Pad1.33x1.80mm_HandSolder
C14, C16: 10u; C_1206_3216Metric_Pad1.33x1.80mm_HandSolder
D2: SS34LW; SODFL3718X102N; PARTREV S2311
D3: 1N4007FL; CR_SOD-123FL_SME-M
D4: LED; LED_0603_1608Metric_Pad1.05x0.95mm_HandSolder
F1, F2: Fuse; FUSE_SMDF050-2
J9: Powerjack; CONN_OSTVN02A150_OST
J10: Piles; CONN_OSTVN02A150_OST
L1: 6.8u; TMPA 0603S
Q3: PJA3432-AU_R1; SOT-23_Handsoldering
Q4: DMP3068L; SOT-23_Handsoldering
R16, R19, R20, R23: 10k; R_0805_2012Metric_Pad1.20x1.40mm_HandSolder
R17: 34.8k; R_0805_2012Metric_Pad1.20x1.40mm_HandSolder
R18, R22: 100; R_0805_2012Metric_Pad1.20x1.40mm_HandSolder
R21: 51k; R_0805_2012Metric_Pad1.20x1.40mm_HandSolder
R24: 232k; R_0805_2012Metric_Pad1.20x1.40mm_HandSolder
R25: 510k; R_0805_2012Metric_Pad1.20x1.40mm_HandSolder
R26: 1.5k; R_1206_3216Metric_Pad1.30x1.75mm_HandSolder
R27: 0R; R_0805_2012Metric_Pad1.20x1.40mm_HandSolder
TP3, TP4, TP5, TP6, TP7, TP8: TP420X150
TP9: BOOST; PinHeader_1x02_P2.54mm_Vertical
TP15: 5V; PinHeader_1x02_P2.54mm_Vertical
U4: PAM2423AECADJR; SOP-8_PAM2423AECADJR_DIO-M
U5: MIC2940A-5.0WT 5V; TO-220-3_Vertical

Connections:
+5V: C14.1, R26.2, TP6.1, TP15.1, U5.3 (VOUT); also elsewhere on the board
BATT_MON: C16.1, R24.1, R25.2; also elsewhere on the board
BOOST_IN: C7.1, C8.1, C9.1, F2.2, L1.1, R16.2, R24.2, TP3.1, U4.2 (VIN)
BOOST_OUT: Q4.3 (D), R27.2
GND: C5.2, C6.2, C7.2, C8.2, C9.2, C10.2, C11.2, C12.2, C13.2, C14.2, C16.2, D4.1 (K), J9.1, J10.1, Q3.2 (S), R19.1, R20.2, R23.1, R25.1, TP7.1, TP9.2, TP15.2, U4.1 (PGND), U4.5 (AGND), U4.EPAD, U5.2 (GND); also elsewhere on the board
unnamed: C12.1, R21.1
unnamed: D4.2 (A), R26.1
unnamed: F1.1, J9.2
unnamed: F2.1, J10.2
unnamed: Q3.3 (D), R16.1, U4.3 (EN)
unnamed: Q3.1 (G), R18.1, R20.1
unnamed: Q4.1 (G), R22.2, R23.2
unnamed: C13.1, D3.1, Q4.2 (S), TP8.1, U5.1 (VIN)
unnamed: C5.1, C6.1, D2.C, R17.2, R27.1, TP4.1, TP9.1
unnamed: C11.1, R21.2, U4.4 (COMP)
unnamed: R17.1, R19.2, U4.6 (FB)
unnamed: C10.1, U4.7 (SS)
unnamed: D2.A, L1.2, U4.8 (SW)
VDC: D3.2, F1.2, R18.2, R22.1, TP5.1

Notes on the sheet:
Vers régulateur découplage
Alimentation
Régulateur à découplage
TMPA 0603S

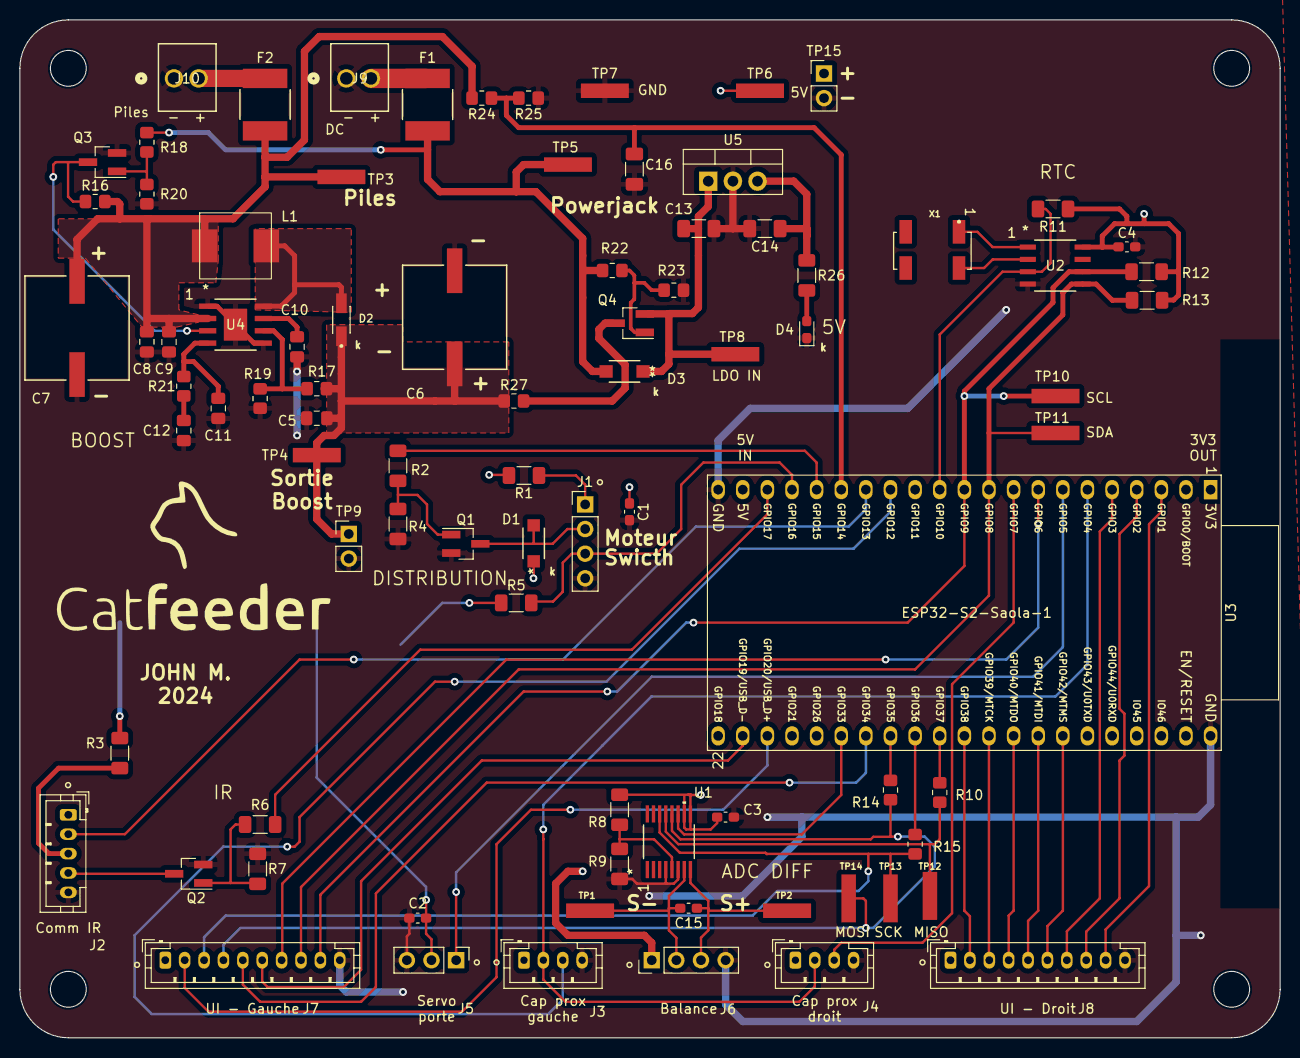
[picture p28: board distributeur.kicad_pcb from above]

Board: 2 copper layers, 130.0 x 105.0 mm, 85 parts (0 on the bottom side), 61 nets.

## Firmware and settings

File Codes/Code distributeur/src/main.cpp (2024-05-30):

#include <Arduino.h>
#include <IRremote.h> 
#include <ESP32Servo.h>
#include <SPI.h>
#include <U8g2lib.h>
#include <pins.h>
#include <svg.h>
#include <WiFi.h>
#include <DNSServer.h>
#include <DS1337RTC.h>
#include <Time.h>
#include <Wire.h>
#include <AsyncTCP.h>
#include "ESPAsyncWebServer.h"
#include <Preferences.h>
#include <WiFiUdp.h>
#include <SPIFFS.h>
#include <VL53L0X.h>
#include <InfluxDbClient.h>
#include <InfluxDbCloud.h>

//flags systeme
bool criticalError = false;

//flash
Preferences prefs;

//influxDB
#define INFLUXDB_URL "https://us-east-1-1.aws.cloud2.influxdata.com"
#define INFLUXDB_TOKEN "P-XKFBBsabdrrz6JTpTMCTRgBIhvIcKQ2_bM9OfujZ7qn-Eo1fvZDOpx9zOarQtTL-KAlQDnRNWM1vsuwkO2dA=="
#define INFLUXDB_ORG "b42d947af9eaac69"
#define INFLUXDB_BUCKET "Weight_real"
InfluxDBClient client(INFLUXDB_URL, INFLUXDB_ORG, INFLUXDB_BUCKET, INFLUXDB_TOKEN, InfluxDbCloud2CACert);
Point weight_DB("weight");

//balance 
// conversion speeds ((Continuous) Samples Per Second)
//single:
#define MAX_CMD_CONV    0x80        // 0b10000000
#define MAX_SPS_1       0x00
#define MAX_SPS_2_5     0x01
#define MAX_SPS_5       0x02
#define MAX_SPS_10      0x03
#define MAX_SPS_15      0x04
#define MAX_SPS_30      0x05
#define MAX_SPS_60      0x06
#define MAX_SPS_120     0x07
// continuous:
#define MAX_CSPS_60     0x04
#define MAX_CSPS_120    0x05
#define MAX_CSPS_240    0x06
#define MAX_CSPS_480    0x07
// registers: 
#define MAX_CMD_REG     0xC0        // 0b11000000
// register addresses:
#define MAX_STAT1       0x00 << 1
#define MAX_CTRL1       0x01 << 1
#define MAX_CTRL2       0x02 << 1
#define MAX_CTRL3       0x03 << 1
#define MAX_DATA        0x04 << 1
#define MAX_SOC         0x05 << 1
#define MAX_SGC         0x06 << 1
#define MAX_SCOC        0x07 << 1
#define MAX_SCGC        0x08 << 1
#define MAX_READ        0x01
#define MAX_WRITE       0x00
#define MAX_UNIPOLAR    0x40        // input range: defaults to bipolar (-AREF to +AREF). UNI = (0 to +AREF)
#define MAX_CONTCONV    0x02        // defaults to single-conversion. FYI the first 3 data from continuous are incorrect. 
float weight_g = 0;
int weight_ADC = 0;
int ADC_tare = 0;
float const calibration = 21.4;  //bits par gramme
bool weightToBeUpdated = false;
int weightToBeUpdated_counter = 0;

//WiFi
bool wifiConnected = false;
bool networkConnected = false;
String ssid     = "SSID";
String password = "password";
DNSServer dnsServer;
AsyncWebServer server(80);
bool WifiCredentialsSet = false;
bool WifiSTA = true; //configuration normale ou sinon AP pour la config
bool upANDdownActivated = false; //si bouton hautet bas sont enfoncé
bool upActivated = true;
int millisupAcivated = 0;
int timerupANDdownActivated = 0;
bool startBroadcast = false;
bool verifyNetwork = false; //a chaque minute on vérifie si on a perdu le réseau
bool checkReconnectNetwork = false; //si on est reconnecté on se reconnecteur au temps et influxdb

//Time & RTC
String hourNow = "00:00";
String hourNew = "00:00";
int RTCTimeHour = 0;
int RTCTimeMinutes =  0;
int RTCTimeSeconds = 0; 
const char* ntpServer = "pool.ntp.org";
const long  gmtOffset_sec = 0;
int   Offset_sec = -14400; //-4h
tmElements_t tm;
bool alarmRTC = false;
bool updateTimeFlag = false;
bool timeChanged = false; //si hourNew doit updater hourNow
int timezoneIndex = 12;
String timeZoneNames[] = {
      "UTC-12:00", "UTC-11:30", "UTC-11:00", "UTC-10:30", "UTC-10:00",
      "UTC-09:30", "UTC-09:00", "UTC-08:30", "UTC-08:00", "UTC-07:00",
      "UTC-06:00", "UTC-05:00", "UTC-04:00", "UTC-03:30", "UTC-03:00",
      "UTC-02:00", "UTC-01:00", "UTC+00:00", "UTC+01:00", "UTC+02:00",
      "UTC+03:00", "UTC+03:30", "UTC+04:00", "UTC+04:30", "UTC+05:00",
      "UTC+05:30", "UTC+05:45", "UTC+06:00", "UTC+06:30", "UTC+07:00",
      "UTC+08:00", "UTC+08:30", "UTC+08:45", "UTC+09:00", "UTC+09:30",
      "UTC+10:00", "UTC+10:30", "UTC+11:00", "UTC+11:30", "UTC+12:00",
      "UTC+12:45", "UTC+13:00", "UTC+13:45", "UTC+14:00"
};

// Tableau des décalages horaires
float timeZoneOffsets[] = {
    -12.0f, -11.5f, -11.0f, -10.5f, -10.0f, -9.5f, -9.0f, -8.5f, -8.0f,
    -7.0f, -6.0f, -5.0f, -4.0f, -3.5f, -3.0f, -2.0f, -1.0f, 0.0f, 1.0f,
    2.0f, 3.0f, 3.5f, 4.0f, 4.5f, 5.0f, 5.5f, 5.75f, 6.0f, 6.5f, 7.0f,
    8.0f, 8.5f, 8.75f, 9.0f, 9.5f, 10.0f, 10.5f, 11.0f, 11.5f, 12.0f,
    12.75f, 13.0f, 13.75f, 14.0f
};

//capteur de distance
VL53L0X sensor;
const int distanceMin = 340;
int distances[3] = {0,0,0};
uint8_t distancesIndex = 0;

//servo-porte
Servo myservo;
bool doorOpened = false; //flag si porte ouverte
bool doorOpenedByCat = false; //flag si porte ouverte par chat
bool doorOpenedByManually = false; //flag si porte ouverte manuellement
int counterDoorOpenCatLeft = 0; //compte le nb de seconde depuis que le chat est parti

//Communication IR
enum StatesComm  {STANDBY, TX_COMM, RX_COMM, CAT_EATING};
StatesComm stateComm = STANDBY;
int counterTXUptime = 0;
int counterRXUptime = 0;
int millisCommIR = 0;
int tagID = 0x00;

//Portions
int lastFeeding = 1;
int lastNbFeeding = 0;
String timeFeeding1 = "08:00";
int nbFeeding1 = 0;
String timeFeeding2 = "17:00";
int nbFeeding2 = 0;

//Batteries
uint8_t batTag = 0; //batterie balise 0 à 255
uint8_t batDis = 0; //batterie distributeur 0 à 255
bool lowBattery = false;
bool readBattery = false;
int timerLowBattery = 0; //timer RGB flash rouge si batterie presque vide

//Interface utilisateur
U8G2_SSD1322_NHD_256X64_F_4W_SW_SPI u8g2(U8G2_R0, /* clock=*/PIN_SCK, /* data=*/PIN_MOSI, /* cs=*/PIN_CS_SCREEN, /* dc=*/PIN_DC_SCREEN, /* reset=*/PIN_RESET_SCREEN); // Enable U8G2_16BIT in u8g2.h
enum Menus  {SCREEN_OFF, NAVIGATION_MENU, MAIN_MENU, PORTIONS_MENU, HOUR_MENU, ACTIONS_MENU};
Menus menu_selected = MAIN_MENU;
int Item_selected_row = 1;
int Item_selected_column = 1;
int feedingSelected = 1;
bool keypad_up = false;
bool keypad_down = false;
bool keypad_left = false;
bool keypad_right = false;
bool keypad_select = false;
long lastDebounceTime = 0;  // the last time the output pin was toggled
long debounceDelay = 100;    // the debounce time; increase if the output flickers
int lastMinutes; //dernière minutes pour savoir si on rafraichi l'heure
int timerScreenNoActivity = 0;
bool screenON = false;
int powerLEDTimer = 0;
bool powerLEDON = true;
bool tagAddingLED = false;
bool tagAddingLED_status = false;
bool tagAddedLED = false;
int tagAddedLED_counter = 0;

uint8_t RGB_R = 0;
uint8_t RGB_G = 0;
uint8_t RGB_B = 0;
uint8_t RGB_R_Last = 0;
uint8_t RGB_G_Last = 0;
uint8_t RGB_B_Last = 0;


// Timer
hw_timer_t *timer = NULL;
volatile bool interruptbool1 = false;
int timerSecond =  0; //pair si timer tombe sur 1 seconde

/*0(off) à 255(on)*/
void setRGB(uint8_t r, uint8_t g, uint8_t b){
  RGB_R_Last = RGB_R;
  RGB_G_Last = RGB_G;
  RGB_B_Last = RGB_B;
  RGB_R = r;
  RGB_G = g;
  RGB_B = b;
  r = (((float)(255-r))/255)*140 + 115; //réduis intensité
  g = (((float)(255-g))/255)*140 + 115;
  b = (((float)(255-b))/255)*140 + 115;
  /*Serial.println(r);
  Serial.println(g);
  Serial.println(b);*/
  analogWrite(PIN_RGB_R, r);
  analogWrite(PIN_RGB_G, g);
  analogWrite(PIN_RGB_B, b);
}

/*remets la RGB à ce qu'elle était avant*/
void setRGBlast(){
  uint8_t r = (((float)(255-RGB_R_Last))/255)*140 + 115; //réduis intensité
  uint8_t g = (((float)(255-RGB_G_Last))/255)*140 + 115;
  uint8_t b = (((float)(255-RGB_B_Last))/255)*140 + 115;
  analogWrite(PIN_RGB_R, r);
  analogWrite(PIN_RGB_G, g);
  analogWrite(PIN_RGB_B, b);
}

void IRAM_ATTR onTimer()  //compteur de 500ms
{
  interruptbool1 = true; // Indicates that the interrupt has been entered since the last time its value was changed to false

  if(WifiSTA){ //mdde normal
    if(timerSecond % 300 == 0){ //5 minute
      readBattery = true;
    }
    if(timerSecond % 30 == 0){ //30sec
      verifyNetwork = true;
    }
    if(timerSecond % 2 == 0){ //1 seconde
      if(tagAddedLED){
        if(tagAddedLED_counter>=2){
          setRGB(0,0,0);
          tagAddedLED = false;
        }
        else{
          tagAddedLED_counter++;
        }
      }

      if(weightToBeUpdated){
        weightToBeUpdated_counter++;
      }
      
      if(upANDdownActivated){
        timerupANDdownActivated++;
      }
      if(stateComm == RX_COMM){
        counterRXUptime++;
      }
      if(doorOpenedByCat){
        counterDoorOpenCatLeft++;
      }
      updateTimeFlag = true;
      if(screenON){
        timerScreenNoActivity++;
      }
      if(powerLEDON){ //ferme led après 5 sec
        powerLEDTimer ++ ;
        if(powerLEDTimer == 5){
          setRGB(0,0,0);
        }
      }
      if(lowBattery){
        timerLowBattery++;
      }
    }
    if(stateComm == TX_COMM){
      counterTXUptime++;
    }
    //flash 500ms del jaune ajout balise
    if(tagAddingLED){
      if(tagAddingLED_status){
        setRGB(0,0,0); //off
        tagAddingLED_status = false;
      }else{
        setRGB(255,255,0); //jaune
        tagAddingLED_status = true;
      }
    }

    //counter de secondes
    timerSecond++;
  }
}

void keypadUPInterrupt(){
  if((millis() - lastDebounceTime) > debounceDelay && (menu_selected == HOUR_MENU || menu_selected == ACTIONS_MENU || menu_selected == PORTIONS_MENU)){
    keypad_up = true;
    lastDebounceTime = millis();
  }
}

void keypadDOWNInterrupt(){
  if((millis() - lastDebounceTime) > debounceDelay && (menu_selected == HOUR_MENU || menu_selected == ACTIONS_MENU || menu_selected == PORTIONS_MENU)){
    keypad_down = true;
    lastDebounceTime = millis();
    timerScreenNoActivity = 0;
  }
}

void keypadLEFTInterrupt(){
  if((millis() - lastDebounceTime) > debounceDelay && (menu_selected == HOUR_MENU || menu_selected == NAVIGATION_MENU || menu_selected == ACTIONS_MENU || menu_selected == PORTIONS_MENU)){
    keypad_left = true;
    lastDebounceTime = millis();
    timerScreenNoActivity = 0;
  }
}

void keypadRIGHTInterrupt(){
  if((millis() - lastDebounceTime) > debounceDelay && (menu_selected == HOUR_MENU || menu_selected == NAVIGATION_MENU || menu_selected == ACTIONS_MENU || menu_selected == PORTIONS_MENU)){
    keypad_right = true;
    lastDebounceTime = millis();
    timerScreenNoActivity = 0;
  }
}

void keypadSELECTInterrupt(){
  if((millis() - lastDebounceTime) > debounceDelay){
    keypad_select = true;
    lastDebounceTime = millis();
    timerScreenNoActivity = 0;
  }
}

void alarmRTCInterrupt(){
  alarmRTC = true;
}


class CaptiveRequestHandler : public AsyncWebHandler
{
public:
  CaptiveRequestHandler() {}
  virtual ~CaptiveRequestHandler() {}

  bool canHandle(AsyncWebServerRequest *request)
  {
    // request->addInterestingHeader("ANY");
    return true;
  }

  void handleRequest(AsyncWebServerRequest *request)
  {
    request->send(SPIFFS, "/index.html", "text/html");
  }
};

void setupServer()
{
  server.on("/", HTTP_GET, [](AsyncWebServerRequest *request)
            { request->send(SPIFFS, "/index.html", "text/html"); 
            Serial.println("Client Connected"); });

  server.on("/get", HTTP_GET, [](AsyncWebServerRequest *request)
            {
      String inputMessage;
      String inputParam;
  
      if (request->hasParam("ssid")) {
        inputMessage = request->getParam("ssid")->value();
        inputParam = "ssid";
        ssid = inputMessage;
        prefs.putString("ssid", inputMessage);
        Serial.println(inputMessage);
      }

      if (request->hasParam("password")) {
        inputMessage = request->getParam("password")->value();
        inputParam = "password";
        password = inputMessage;
        prefs.putString("password", inputMessage);
        Serial.println(inputMessage);
      }
      request->send(200, "text/html", "The values entered by you have been successfully sent to the device <br><a href=\"/\">Return to Home Page</a>");
      WifiCredentialsSet = true; });
}

void connectWiFi()
{
  WiFi.persistent(false);
  WiFi.disconnect();
  WiFi.mode(WIFI_STA);
  WiFi.persistent(true);
  Serial.print("Connecting to ");
  Serial.println(ssid);
  WiFi.begin(ssid.c_str(), password.c_str());
  int nbTries = 0;
  while (WiFi.status() != WL_CONNECTED && nbTries<15) { //timeout
    delay(500);
    Serial.print(".");
    nbTries++;
  }
  if(WiFi.status() == WL_CONNECTED){ //imprime info si connecté
    Serial.println("");
    Serial.println("WiFi connected.");
    wifiConnected = true;
    Serial.println(WiFi.localIP());
  }
  else{
    Serial.println("Unable to connect to WiFi");
    wifiConnected = false;
  }
}

void reconnectNetwork(){
  //----------------------------------------------------Time & RTC
  bool timeGood = true;
  if(WiFi.status() == WL_CONNECTED){
    Offset_sec = timeZoneOffsets[timezoneIndex]*60*60;
    configTime(gmtOffset_sec, Offset_sec, ntpServer); //récupère l'heure d'internet
    struct tm timeinfo;
    if(!getLocalTime(&timeinfo)){
      Serial.println("Failed to obtain time");
      timeGood = getLocalTime(&timeinfo);
      Serial.println("Failed to obtain time again!");
    }else if(timeGood){
      tm.Year = timeinfo.tm_year - 70;
      tm.Month = timeinfo.tm_mon + 1;
      tm.Day = timeinfo.tm_mday;
      tm.Hour = timeinfo.tm_hour;
      tm.Minute = timeinfo.tm_min;
      tm.Second = timeinfo.tm_sec;
    Serial.print(tm.Hour);
    Serial.print(tm.Minute);
    Serial.println(tm.Second);

    RTC.set(makeTime(tm), CLOCK_ADDRESS);
    
    Serial.print("DS1337 configured Hour=");
    Serial.print(tm.Hour);
    Serial.print(", Minutes=");
    Serial.println(tm.Minute);
    }
  }
  if (client.validateConnection()) {
    Serial.print("Connected to InfluxDB: ");
    Serial.println(client.getServerUrl());
    if(timeGood){ //si serveur temps et influxdb good
      networkConnected = true;
      Serial.println("Connected to network fully");
    }
  } else {
    Serial.print("InfluxDB connection failed: ");
    Serial.println(client.getLastErrorMessage());
  }
}
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
void loop()
{

  if(WifiSTA){
    //vérifier connection réseau
    if(verifyNetwork){
      checkReconnectNetwork = false;
      if(WiFi.status() != WL_CONNECTED ){//si on  est plus connecté
        WiFi.begin(ssid.c_str(), password.c_str());
        Serial.println("trying to reconnect to wifi...");
        if(wifiConnected && menu_selected == MAIN_MENU){ //on était connecté au wifi avant et on est sur la page d'accueil 
          wifiConnected = false;
          networkConnected = false;
          printMenu(menu_selected);
        }
        checkReconnectNetwork = true;
        wifiConnected = false;
        networkConnected = false;
      }
      verifyNetwork = false;
    }
    if(checkReconnectNetwork){
      if(WiFi.status() == WL_CONNECTED ){//si on devient connecté
        checkReconnectNetwork = false;
        wifiConnected = true;
        reconnectNetwork();
        if(menu_selected == MAIN_MENU){ //on est sur la page d'accueil
          printMenu(menu_selected);
        }
        Serial.println("Wifi recconnected!");
      }
    }

    //battery ADC
    if(readBattery){
    batDis = (float)analogRead(PIN_BATT_MON) / 4.0 ; //niveau batterie distributeur 0 à 255
    Serial.print("batDis: ");
    Serial.println(batDis);
    if(batDis < 76){ //30%
      lowBattery = true;
    }
    else{
      lowBattery = false;
    }
    readBattery = false;
    }
    if(lowBattery && timerLowBattery >= 300 && !(RGB_R==255 && RGB_G==0 && RGB_B==0)){//allume RGB rouge si batterie vide au 5 minute
      setRGB(255,0,0);
      Serial.println("Open RGB low battery");
    }
    if(lowBattery && timerLowBattery >= 305 && (RGB_R==255 && RGB_G==0 && RGB_B==0)){//5 seconde plus tard on remets la led
      setRGBlast();
      timerLowBattery = 0;
      Serial.println("Close RGB low battery");
    }

    //update poids 
    if(weightToBeUpdated && weightToBeUpdated_counter >3){
      weightToBeUpdated = false;
      weightToBeUpdated_counter = 0;
      updateWeight();
    }

    //reset poids balance
    int up = digitalRead(PIN_BUT_UP);
    int down = digitalRead(PIN_BUT_DOWN);
    if(up==0 && down == 1){
      if(upActivated && (millis() - millisupAcivated) > 5000){
        setRGB(255,125,255); //rose pale
        weight_g = 0;
        weight_ADC = getWeight();
        ADC_tare = weight_ADC;
        prefs.putInt("ADC_tare", ADC_tare);
        prefs.putFloat("weight_g", weight_g);
        prefs.putInt("weight_ADC", weight_ADC);
        sendToInfluxDB();
        Serial.println("Weight reseted");
        Serial.println("weight_g : " + (String)weight_g);
        Serial.println("weight_ADC : " + (String)weight_ADC);
        upActivated = false;
        setRGB(0,0,0);
      }else if(!upActivated){
        upActivated = true;
        millisupAcivated = millis();
      }
    }else{
      upActivated = false;
    }

    //lecture bouton haut bas
    if(up == 0 && down == 0){
      if(!upANDdownActivated && !startBroadcast){ //appui débuté
        upANDdownActivated = true;
        timerupANDdownActivated = 0;
      }
      if(upANDdownActivated && timerupANDdownActivated >= 3){ //appui fin 3 sec
        startBroadcast = true;
        upANDdownActivated = false;
      }
    }else if(upANDdownActivated){ //appui arreté avant fin
      upANDdownActivated = false;
    }

    //Heure RTC
    if(updateTimeFlag){ //update chaque seconde
      updateTime();
      updateTimeFlag = false;
    }
    if(alarmRTC){
      Serial.println("ALARM!!!!");
      alarmRTC = false;
      RTC.resetAlarms();
      int nbFeeding = 0;
      String h = hourNow.substring(0,2);
      if(h==timeFeeding1.substring(0,2)){ //hours ok
        int mH = hourNow.substring(3,5).toInt(); //check minutes (décalage possible)
        int mF = timeFeeding1.substring(3,5).toInt();
        if((mH == mF) || (mH+1 == mF) || (mH == 59 && mF==00)){
          nbFeeding = nbFeeding1;
          lastFeeding = 1;
          prefs.putInt("lastFeeding", lastFeeding);
          Serial.println("lastFeeding : " + (String)lastFeeding);
          lastNbFeeding = nbFeeding;
          prefs.putInt("lastNbFeeding", lastNbFeeding);
          Serial.println("lastNbFeeding : " + (String)lastNbFeeding);
          if(menu_selected == MAIN_MENU){ //on est sur la page d'accueil
            printMenu(menu_selected);
          }
        }
      }
      else if(h==timeFeeding2.substring(0,2)){ //hours ok
        int mH = hourNow.substring(3,5).toInt(); //check minutes (décalage possible)
        int mF = timeFeeding2.substring(3,5).toInt();
        if((mH == mF) || (mH+1 == mF) || (mH == 59 && mF==00)){
          nbFeeding = nbFeeding2;
          lastFeeding = 2;
          prefs.putInt("lastFeeding", lastFeeding);
          Serial.println("lastFeeding : " + (String)lastFeeding);
          lastNbFeeding = nbFeeding;
          prefs.putInt("lastNbFeeding", lastNbFeeding);
          Serial.println("lastNbFeeding : " + (String)lastNbFeeding);
          if(menu_selected == MAIN_MENU){ //on est sur la page d'accueil
            printMenu(menu_selected);
          }
        }
      }
      
      for(int i=0; i<nbFeeding; i++){
        distribute();
        delay(100);
      }
      weightToBeUpdated = true;
    }  

    //Comm IR
    if((!doorOpened || stateComm == CAT_EATING) && !tagAddedLED){
      stateMachineComm();
    }

    //Écran fermé
    if(timerScreenNoActivity >120 && screenON){
      Serial.println("Screen turned off");
      u8g2.sleepOn();
      screenON = false;
      menu_selected = SCREEN_OFF;
    }

    //Écran
    stateMachineScreen();

    //start AP broadcast
    if (startBroadcast)
    {
      WifiSTA = false;
      Serial.println();
      Serial.println("Setting up AP Mode");
      WiFi.mode(WIFI_AP);
      WiFi.softAP("CatFeeder_0001", "12345678");
      Serial.print("AP IP address: ");
      Serial.println(WiFi.softAPIP());
      Serial.println("Setting up Async WebServer");
      setupServer();
      Serial.println("Starting DNS Server");
      dnsServer.start(53, "*", WiFi.softAPIP());
      server.addHandler(new CaptiveRequestHandler()).setFilter(ON_AP_FILTER); // only when requested from AP
      server.begin();
      Serial.println("All Done!");
      u8g2.sleepOff();
      u8g2.clearBuffer();
      u8g2.setFont(u8g2_font_helvR14_tr);
      u8g2.drawStr(0, 17, "SSID: CatFeeder_0001");
      u8g2.drawStr(0, 50, "mdp: 12345678");
      u8g2.sendBuffer();
      setRGB(255,140,0); //orange
    }

  }else{
    // Access point
    dnsServer.processNextRequest();
    if (WifiCredentialsSet || digitalRead(PIN_BUT_SELECT) == LOW)
    {
      u8g2.clearBuffer();
      u8g2.drawXBMP(76, 0, 103, 64, logo);
      u8g2.sendBuffer();
      connectWiFi();
      bool timeGood = true;
      if(WiFi.status() == WL_CONNECTED){
      Offset_sec = timeZoneOffsets[timezoneIndex]*60*60;
      configTime(gmtOffset_sec, Offset_sec, ntpServer); //récupère l'heure d'internet
      struct tm timeinfo;
      if(!getLocalTime(&timeinfo)){
        Serial.println("Failed to obtain time");
        timeGood = getLocalTime(&timeinfo);
        Serial.println("Failed to obtain time again!");
      }else if(timeGood){
        tm.Year = timeinfo.tm_year - 70;
        tm.Month = timeinfo.tm_mon + 1;
        tm.Day = timeinfo.tm_mday;
        tm.Hour = timeinfo.tm_hour;
        tm.Minute = timeinfo.tm_min;
        tm.Second = timeinfo.tm_sec;
      }
      Serial.print(tm.Hour);
      Serial.print(tm.Minute);
      Serial.println(tm.Second);

      RTC.set(makeTime(tm), CLOCK_ADDRESS);
      
      Serial.print("DS1337 configured Hour=");
      Serial.print(tm.Hour);
      Serial.print(", Minutes=");
      Serial.println(tm.Minute);
    }
    if(WifiCredentialsSet){
      prefs.putBool("wifiInitialized", true);
    }
      WifiSTA = true;
      WifiCredentialsSet = false;
      setRGB(0, 0, 0);
      keypad_up = false;
      keypad_down = false;
      keypad_left = false;
      keypad_right = false;
      keypad_select = false;
      startBroadcast= false;
      menu_selected = MAIN_MENU;
      printMenu(menu_selected);
      screenON = true;
      timerScreenNoActivity = 0;
    }
  }
}
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

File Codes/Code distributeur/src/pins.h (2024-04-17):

/*PINS*/

//Batterie
#define PIN_BATT_MON 14      //lecture voltage batterie

//Boutons
#define PIN_BUT_UP 42        //bouton haut
#define PIN_BUT_DOWN 2       //bouton bas
#define PIN_BUT_LEFT 41      //bouton gauche
#define PIN_BUT_RIGHT 1      //bouton droit
#define PIN_BUT_SELECT 3     //bouton sélection

//Écran
#define PIN_DC_SCREEN 20     //DC écran
#define PIN_CS_SCREEN 19     //chip select écran
#define PIN_RESET_SCREEN 34  //reset écran

//RGB
#define PIN_RGB_R 40         //RGB rouge
#define PIN_RGB_G 38         //RGB vert
#define PIN_RGB_B 39         //RGB bleu

//IR
#define PIN_IR_RX 13         //photorécepteur
#define PIN_IR_TX 17         //DEL IR

//Capteur de proximité
#define PIN_OUT_PROX_1 12    //photorécepteur capteur de proximité 1
#define PIN_OUT_PROX_2 7     //photorécepteur capteur de proximité 2
#define PIN_IN_PROX 4        //DEL capteurs de proximité (même signal pour les deux)

//Capteur de distance
#define PIN_XSHUT_DIST 6       //xshut capteur de distance

//Comm série
#define PIN_SDA 8            //SDA
#define PIN_SCL 9            //SCL
#define PIN_MOSI 35          //MOSI
#define PIN_MISO 37          //MISO
#define PIN_SCK 36           //SCK

//ADC balance
#define PIN_CS_ADC_SCALE 33  //chip select adc différentiel

//RTC
#define PIN_INT_RTC 10       //interrupt RTC

//Servo porte
#define PIN_SERVO 5          //servomoteur porte

//Distribution
#define PIN_MOTOR_DIST 15    //activation moteur distribution
#define PIN_SWITCH_DIST 16   //rétroaction moteur distribution

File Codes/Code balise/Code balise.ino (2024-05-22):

#include <avr/sleep.h>
#include <avr/interrupt.h>

//pins
const int switchPin = 3;
const int pinBatMon = 4;


uint8_t adress = 0x12;
uint8_t command = 0x00;

int battery = 0;
int adcReadNb = 0;

void sleep() {

    GIMSK |= _BV(PCIE);                     // Enable Pin Change Interrupts
    PCMSK |= _BV(PCINT3);                   // Use PB3 as interrupt pin
    ADCSRA &= ~_BV(ADEN);                   // ADC off
    set_sleep_mode(SLEEP_MODE_PWR_DOWN);    // replaces above statement

    sleep_enable();                         // Sets the Sleep Enable bit in the MCUCR Register (SE BIT)
    sei();                                  // Enable interrupts
    sleep_cpu();                            // sleep

    cli();                                  // Disable interrupts //wake-ups here
    PCMSK &= ~_BV(PCINT3);                  // Turn off PB3 as interrupt pin
    sleep_disable();                        // Clear SE bit
    ADCSRA |= _BV(ADEN);                    // ADC on

    sei();                                  // Enable interrupts
    } // sleep

ISR(PCINT0_vect) {
    
    }

void sendNEC(){
  //start
  TCCR0A = 0b01010010;
  OCR0A = 13; //pour regler 38khz
  _delay_us(9500);
  TCCR0A = 0b00000000;
  _delay_us(2950);

  //adress
  for (int i = 0; i < 8; i++) {
    if (bitRead(adress, i) == 1) { //1
      TCCR0A = 0b01010010;
      _delay_us(575);
      TCCR0A = 0b00000000;
      _delay_us(1050);
    }
    else {                        //0
      TCCR0A = 0b01010010;
      _delay_us(575);
      TCCR0A = 0b00000000;
      _delay_us(365);
    }
  }
  for (int i = 0; i < 8; i++) { //inverted
    if (bitRead(adress, i) == 0) { //0
      TCCR0A = 0b01010010;
      _delay_us(575);
      TCCR0A = 0b00000000;
      _delay_us(1050);
    }
    else {                        //1
      TCCR0A = 0b01010010;
      _delay_us(575);
      TCCR0A = 0b00000000;
      _delay_us(365);
    }
  }

  //command
  for (int i = 0; i < 8; i++) {
    if (bitRead(command, i) == 1) { //1
      TCCR0A = 0b01010010;
      _delay_us(575);
      TCCR0A = 0b00000000;
      _delay_us(1050);
    }
    else {                        //0
      TCCR0A = 0b01010010;
      _delay_us(575);
      TCCR0A = 0b00000000;
      _delay_us(365);
    }
  }
  for (int i = 0; i < 8; i++) { //inverted
    if (bitRead(command, i) == 0) { //0
      TCCR0A = 0b01010010;
      _delay_us(575);
      TCCR0A = 0b00000000;
      _delay_us(1050);
    }
    else {                        //1
      TCCR0A = 0b01010010;
      _delay_us(575);
      TCCR0A = 0b00000000;
      _delay_us(365);
    }
  }

  //stop
  TCCR0A = 0b01010010;
  _delay_us(600);
  TCCR0A = 0b00000000;
  _delay_us(1000);
}

/*appeler juste sur chg de pile*/
void setup() {
  //wakeup piŉ
  pinMode(switchPin, INPUT);
  digitalWrite(switchPin, HIGH);
  //digitalWrite(switchPin, HIGH);
  pinMode(pinBatMon, INPUT);
  
  //PWM 38KHZ on PB0
  TCCR0B = TCCR0B & 0b11111000 | 0b001; //set timer prescaler
  //TCCR0A = 0b01010010; //changer le counter
  //OCR0A = 13; //pour regler 38khz
  DDRB = DDRB & 0b11111110 | 0b00000001; //set pin 0 as output

  //ADC battery
  battery = analogRead(pinBatMon) - 568; //0 à 398 parce que batterie est tjrs plus que 1.8V
  command = ((float)battery / 456) * 255;
  adcReadNb++;

  sendNEC(); //send on battery change
}

void loop() {
  sleep();
  _delay_ms(600); //on attend que RX est fini
  sendNEC();
  _delay_ms(25);
  sendNEC();
  
  //ADC battery
  if(adcReadNb%5 == 0){ // au 5 fois on lit la batterie
  battery = analogRead(pinBatMon) - 568; //0 à 398 parce que batterie est tjrs plus que 1.8V
  command = ((float)battery / 456) * 255;
  }
  adcReadNb++;

}

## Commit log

2024-04-02 print ip
2024-04-03 fix distribution menu action
    [main.cpp]
2024-04-03 servo porte
2024-04-10 comm IR machine etat, BUG chat mange
    [main.cpp]
2024-04-17 rajout cap distance (buggy)
    [main.cpp]
2024-04-17 fix temp cap dist
    [main.cpp]
2024-04-17 door closes when open on reset
    [main.cpp]
2024-04-18 page de connection
2024-04-19 delai meilleur comm IR (millis)
2024-04-19 fix comm IR (close dist cap when ununsed)
    [main.cpp]
2024-04-19 RGB low battery fonctionnel
2024-04-24 démarage de base
2024-04-25 fix lag cap distance
    [main.cpp]
2024-04-25 bus spi plus vite
2024-04-25 adc faster
2024-05-08 update calibration load cell
2024-05-10 fix main menu portions
    [main.cpp]
2024-05-13 prefs ADC tare
2024-05-20 chg timer screen off for demo
2024-05-22 structure github projet plus complet
    [adapteur gougeon.stl, adapteur servo.stl, base réserve bouffe.stl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]
2024-05-30 github repo final
    [3011.step, Balise.kicad_pcb, Balise.kicad_sch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]
